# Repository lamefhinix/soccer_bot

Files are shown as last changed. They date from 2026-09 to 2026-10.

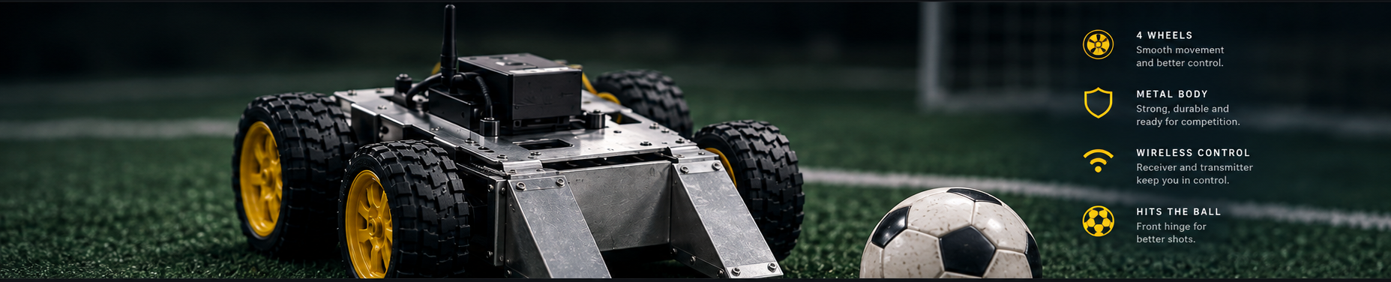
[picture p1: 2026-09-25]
soccer-bot-cover.png

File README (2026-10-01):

description

Soccer Bot is a high-performance four-wheel robot built for competitive soccer matches.
Designed to compete against other powerful robots, it emphasizes power, durability, and precise control.
It uses 500 RPM geared motors, metal wheels, an ESP32 controller, and BTS7960 motor drivers for strong, responsive movement.
The aluminum frame provides a durable yet lightweight foundation.
This project combines mechanical engineering, electronics, wireless control, and software for a reliable, competition-ready soccer robot.

motor driver 


main CPU


Bill of Materials


1.Four pcs 37GB 600 RPM motors

2.four pcs wheels with metal rims

3.20x20 cm PVC frame

4.four pcs Motor Driver 43A BTS7960

5.DC DC Buck Converter LM2596 with Display

6.ESP32 S3 DevKitC1 N16R8 Development Board Dual USB Type C 18650

7.12V 7000mAh (84Wh) Lithium-ion Rechargeable Battery Pack with 40A BMS

8.Radiomaster Pocket Radio Controller (M2) 9.RadioMaster ER6 2.4 GHz ELRS PWM receiver

9.ball-handling mechanisms

10.soldering iron

1.Four pcs 37GB 600 RPM motors


description 
The motors power the robot's wheels, so it can move and turn quickly during a match Estimated price: 8.95 dollars × 4 pcs Buy link: https://electronics.com.bd/12v-500-rpm-high-torque-dc-gear-motor-37gb555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

2.Four pcs 65mm Rubber Wheel With Metal rim

description Four 65 millimeter metal rim wheels with rubber tires. Provide traction and transfer motor power to the ground for movement and turning. Estimated price: 16.25 dollars Buy link: https://radiogearbd.com/product-details/65mm-rubber-wheel-with-metal-rim-4pcs-set-for-robo-soccer

3.20x20 cm PVC frame self-funded
4.four pcs of motor driver 43A BTS7960
**

description BTS7960 motor driver module controls one DC motor, allowing independent speed and direction control Estimated price: 3.98 Doller × 4 pcs Buy link: https://store.roboticsbd.com/imugyrocompass/742-motor-driver-43a-bts7960-robotics-bangladesh.html

5.DC DC Buck Converter LM2596 with Display

description DC-DC buck converter: steps down battery voltage to a stable lower voltage for ESP32 and receiver Estimated price: 3.17 Doller × 1 pcs Buy link: https://store.roboticsbd.com/components/1524-lm2596-dc-dc-step-down-buck-converter-with-digital-tube-display-robotics-bangladesh.html

6.12V 7000mAh (84Wh) Lithium-ion Rechargeable Battery Pack with 40A BMS

description 12 volt 7000 milliamp hour Li-ion rechargeable battery with 40 amp BMS, providing reliable power for robot's motors and electronics Estimated price: 22.77 Doller × 1 pcs Buy link: https://www.daraz.com.bd/products/12v-7000mah-84wh-lithium-ion-rechargeable-battery-pack-with-40a-bms-1000-life-i328284264.html

7.ESP32 S3 DevKitC1 N16R8 Development Board Dual USB Type C


description ESP32 DevKit-C1, main control board that processes receiver commands and controls the four BTS7960 motor drivers for precise speed and direction control. Estimated price: 8.1 Doller × 1 pcs Buy link: https://techshopbd.com/product/esp32-s3-devkitc1-n16r8-development-board-dual-usb-type-c

8.Radiomaster Pocket Radio Controller (M2) ELRS Version

description RadioMaster Pocket M2 ELRS, wireless transmitter used to remotely control the robot's movement and speed Estimated 
price: 71.50 Doller × 1 pcs
Buy link: https://radiomasterrc.com/products/pocket-radio-controller-m2

9.ER4 2.4GHz ELRS PWM Receiver


10.WEMON 936 Soldering Iron 90W Intelligent Digital Display Portable 120~550℃ Adjustable 900M Series tools Kit price: 10.00 dollars × 1 pcs

Estimated total: 198.51 dollars



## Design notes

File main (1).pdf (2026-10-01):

# Robo Soccer Robot

## Product Requirements Document

### Parametric concept, interfaces, and CAD handoff specification

Prepared by Manus AI
Date: 2026-10-01

Design status: concept-level, dimensioned for CAD handoff. Fabrication status: do not manufacture until all placeholder hardware dimensions are measured.

## Contents

Robo Soccer Robot — Product Requirements Document | Manus AI

## 1 Executive summary

This document defines a compact four-wheel-drive robo-soccer platform based on a 200 mm × 200 mm square-tube chassis, 65 mm wheels, four geared motors, four BTS7960 motor drivers, an ESP32-class controller, a 12 V battery, a radio receiver, and a front ball-contact bracket. The design prioritizes a low center of gravity, serviceability, inboard wheels, and a footprint that remains below the 250 mm × 250 mm competition envelope.
The accompanying CAD sources include an editable CadQuery generator and an exported STEP assembly. The assembly shows the major parts, the mechanical stack-up, electronics envelopes, and the major service interfaces. The source intentionally distinguishes fixed, derived, and interface-parameterized dimensions so that a later CAD pass can replace manufacturer-specific details without silently changing the design intent.

The first engineering gate is dimensional verification: measure the actual tube, wheel, motor gearbox, battery, driver heatsink, receiver, and controller before releasing fabrication drawings.

## 2 Product definition

## 2.1 Objective

Build a robust, serviceable robot that can drive, turn, and interact with a soccer ball inside a maximum 250 mm × 250 mm footprint. The robot should keep heavy components low, protect wiring from wheel motion, and expose enough access for rapid battery and electronics service.

## 2.2 Intended use

- Indoor or smooth-field robo-soccer prototype.
- Four-wheel drive with independent motor control.
- Front ball-contact bracket with a nominal 70 mm opening.
- Manual radio control in the first integration phase; autonomous strategy is a future extension.

## 2.3 Success criteria

ID | Target | Acceptance evidence
PR-01 Footprint | ≤ 250 × 250 mm | Measured assembled envelope including wheels and bracket
PR-02 Chassis | 200 × 200 mm | CAD inspection and tape-measure check
PR-03 Drive | 4 independently driven wheels | Bench test of all four channels
PR-04 Serviceability | Battery removable without tools | Remove/install demonstration
PR-05 Stability | CG height ≤ 55 mm target | Mass-property estimate after hardware selection

PR-06 Ball interface | 70 mm nominal opening | Ball-contact fit check
PR-07 Electrical safety | Upstream disconnect | Continuity and fault-isolation test

## 3 System architecture

## 3.1 Coordinate system and design intent

The CAD origin is at the chassis center on the floor-pan reference plane. +X points forward toward the ball bracket, +Y points to the left side of the robot, and +Z points upward. All dimensions in this document and in the CAD source are millimetres unless stated otherwise.
The primary layout is symmetric about both center planes. The two 200 mm longitudinal rails sit at Y = ±90 mm. Two 160 mm cross rails sit at X = ±90 mm, inside the longitudinal rails. The resulting outer structural envelope is 200 mm × 200 mm.

## 3.2 Functional blocks

Block | Function | Interfaces
Energy | Store and distribute 12 V power | Battery, fuse/disconnect, motor-driver power, buck converter
Drive | Convert commands into wheel torque | ESP32 PWM/DIR → BTS7960 → four motors
Control | Run manual-control firmware and future strategy | ESP32, receiver input, serial/ programming header
Motion | Translate wheel torque into field motion | Four wheels, four motor mounts, floor clearance
Ball | Guide/contact the ball at the front | 70 mm opening, low capture bar, replaceable liner

## 4 Mechanical requirements

## 4.1 Global parameters

Parameter | Value | Status | Engineering note
FOOTPRINT_MAX | 250 × 250 | Fixed | Competition envelope limit
CHASSIS_L / CHASSIS_W | 200 / 200 | Fixed | Square-tube outer structure
TUBE | 20 × 20 | Placeholder | Measure actual PVC tube; model currently assumes 20
WHEEL_D | 65 | Fixed | Wheel diameter used for axle height

WHEEL_W | 25 | Fixed by brief | Verify hub protrusion and bore before machining
EDGE_CLEARANCE | 15 | Fixed target | Symmetric inboard wheel placement
MOTOR_D / MOTOR_L | 37 / 63 | Fixed envelope | 37GB-family envelope; gearbox hole pattern remains editable
MOTOR_SHAFT_D / L | 6 / 15 | Placeholder | D-shaft flat orientation matters
BATT_L / W / H | 150 / 45 / 45 | Fixed envelope | 12 V, 7000 mAh envelope from brief; verify connector exit
BTS_L / W / H | 50 / 50 / 40 | Fixed envelope | Simplified board/heatsink solid; verify exact mounting pattern
GROUND_CLEARANCE | ≈ 22 | Derived | 65/2 minus approximately 10 mm chassis drop

## 4.2 Chassis and drivetrain geometry

- Wheel centers are at (X, Y) = (±72.5, ±72.5) mm.
- Track and wheelbase are both 145 mm.
- Wheel axles are nominally collinear at Z = 32.5 mm.
- Wheels are inboard. Outboard wheels would push the envelope to approximately 255 mm across and violate the 250 mm limit.
- Add a 5 mm relief slot in each tube wall at the wheel well after the real wheel and tube geometry are measured.
- Heavy components sit on or near the floor pan. Target CG height is no more than 55 mm.

## 4.3 Motor mount requirements

Each corner uses a mirrored L-bracket made from 3 mm aluminium or printed PETG. The bracket shall provide:
1. A motor face plate with four M3 holes on the measured gearbox pattern.
2. Two vertical-leg M3 adjustment slots allowing approximately ±2 mm axle-height correction.
3. Two M3 through-bolts into the tube using T-nuts or captive nuts.
4. A mount datum that keeps all four axles collinear after adjustment.
5. A replaceable interface between the gearbox and the bracket so motor replacement does not require frame disassembly.

## 5 Electronics and wiring

## 5.1 Placement

The battery is centered at X = 0, Y = 0 on the floor pan. It is held with hook-and-loop and two removable retainers bolted to the cross rails. Four BTS7960 drivers occupy open positions around the battery at nominal centers (±60, 0) and (0, ±60), each on four 10 mm M3 standoffs. This leaves airflow around the heatsinks and keeps high-current motor wiring short.

The ESP32 board, buck converter, and receiver form the controller stack near the front/side service area. The CAD model shows their nominal envelopes, not their exact PCB hole patterns; verify the selected board variants before drilling.

## 5.2 Electrical interface contract

Interface | From | To | Requirement
BAT+ / BAT− | 12 V battery | Fuse/disconnect and power bus | Use a single upstream disconnect; common ground throughout
MOTOR_PWR | 12 V bus | BTS7960 ×4 | Route high-current pairs away from receiver and signal wires
MOTOR_OUT ×4 | BTS7960 | Gear motors | One driver per motor; label left/ right and front/rear
PWM/DIR ×4 | ESP32 | BTS7960 inputs | Use four independent channels; reserve GPIOs in firmware map
5 V LOGIC | Buck converter | ESP32 + receiver | Verify regulator current margin and connector polarity
RC SIGNAL | Receiver | ESP32 | Define PWM/PPM/serial protocol before harness fabrication
DEBUG/PROG | USB/UART header | ESP32 | Accessible without removing battery

## 5.3 Wiring and safety requirements

- Add an appropriately sized fuse or resettable protection upstream of the motor-driver bus.
- Use a keyed or polarized connector for the battery and a physically protected power switch/disconnect.
- Separate high-current motor pairs from receiver antenna and controller signal wiring.
- Provide strain relief at every connector that leaves the floor pan.
- Label all four motor channels at both ends of the harness.
- Confirm motor-driver logic voltage compatibility with the selected ESP32 board.
- Provide a single-point common ground and verify it with a continuity test before powering the controller.

## 6 Software and control requirements

## 6.1 Minimum control behavior

The first firmware milestone shall support:
- Arm/disarm state with an explicit safe default after boot.
- Independent output for four motor channels.
- Radio-loss timeout that commands all motor outputs to zero.
- Battery-voltage telemetry or at least a low-voltage warning input in the architecture.
- Direction and inversion parameters per wheel so wiring orientation is configurable.
- A test mode that spins one motor at a time at low duty cycle.

## 6.2 Future extension points

Reserve software and wiring capacity for wheel-speed sensing, a camera or range sensor, and autonomous ball strategy. These are intentionally not modeled as purchased hardware in the first CAD release.

## 7 CAD deliverable specification

## 7.1 Included source model

The deliverable includes robo_soccer_bot_assembly.step, a real multi-solid STEP assembly that re-imports successfully through a STEP-capable CAD kernel, plus robo_soccer_cad.py, its editable CadQuery generator. The earlier OpenSCAD source remains available as a lightweight parametric reference. The CAD deliverables include:
- Frame rails, floor pan, and service deck.
- Four wheels with hubs and four motor pods.
- Mirrored L-bracket motor mounts with fastener markers.
- Battery envelope and removable retainer rails.
- Four BTS7960 envelopes with standoff markers.
- ESP32, buck, and radio-receiver envelopes.
- Front ball bracket, opening, and low capture bar.
- EXPLODED, SHOW_WHEELS, SHOW_ELECTRONICS, and SHOW_FASTENERS toggles.
Open the STEP file in FreeCAD, Fusion 360, SolidWorks, or another STEP-capable CAD tool. The native CadQuery generator exposes editable interface parameters, including the motor gearbox hole spacing. The accompanying SVG files provide CAD-derived top and isometric views.

## 7.2 Assembly sequence

1. Cut and deburr the two longitudinal and two cross rails.
2. Assemble the square frame and verify 200 mm outer dimensions.
3. Install the floor pan and check that it does not interfere with wheel sweep.
4. Fit the four motor brackets loosely, set axle height, and verify collinearity.
5. Install motors and wheels; rotate by hand through a full revolution.
6. Install battery retainers and confirm tool-free battery removal.
7. Install the four drivers on standoffs with open airflow paths.
8. Install controller stack, receiver, and buck converter.
9. Route and label the harness, then perform continuity checks before energizing.
10. Fit the ball bracket and verify the final footprint remains within 250 mm × 250 mm.

## 8 Verification and test plan

ID | Test | Method | Pass condition
V-01 | Envelope | Measure max X/Y including wheels and bracket | Both ≤ 250 mm
V-02 | Wheel clearance | Rotate each wheel by hand with chassis mounted | No rub or hard spot

V-03 | Axle alignment | Straightedge or datum measurement | All axle centers collinear
V-04 | Battery service | Remove/install without tools | No frame disassembly
V-05 | Driver cooling | Low-speed and sustained bench run | No unsafe heat rise; airflow clear
V-06 | Electrical isolation | Continuity, polarity, and disconnect test | No short; disconnect removes drive power
V-07 | Channel mapping | Run one motor at a time | Correct direction and label
V-08 | Ball interface | Fit intended ball and push against bracket | Stable contact without wheel interference

## 9 Risks, assumptions, and open decisions

## 9.1 High-priority risks

- Actual battery connector and cable-exit dimensions may affect service access.
- The selected motor gearbox hole pattern or shaft geometry may differ from the 37GB-family envelope; the interface is intentionally parameterized.
- BTS7960 mounting details may differ from the simplified 50 × 50 × 40 mm solid.
- The front ball bracket may change the footprint if its liner or capture geometry projects beyond the 250 mm limit.
- PVC tube wall thickness and fastener access may require local reliefs not represented in this concept model.

## 9.2 Open decisions before release to manufacture

1. Confirm the exact motor, wheel, battery, driver, ESP32, buck, and receiver part numbers.
2. Confirm manufacturer-specific interfaces and update the CAD parameters where required.
3. Choose the final tube material and joining method: printed corner blocks, aluminium angle, or direct fasteners.
4. Select fuse rating, wire gauges, connectors, and an emergency disconnect.
5. Confirm field rules for ball size, robot envelope, and allowed materials.
6. Decide whether a protective top cover is required after the first drive test.

## 10 Release checklist

[ ] Manufacturer-specific interfaces verified and editable parameters updated. [ ] CAD assembly opens and exports without geometry collisions.
[ ] Footprint and wheel clearance verified on the assembled prototype.
[ ] Electrical harness labeled, fused, and polarity-checked.
[ ] Safe boot, radio-loss timeout, and one-motor-at-a-time test completed. [ ] Ball bracket and service access approved by the build owner.

## 11 Appendix: parameter handoff

Coordinate system: X forward, Y left/right, Z up

Fixed: CHASSIS_L=200, CHASSIS_W=200, FOOTPRINT_MAX=250, WHEEL_D=65

Derived: WHEEL_X=72.5, WHEEL_Y=72.5, AXLE_Z=32.5

Interfaces to verify: TUBE, wheel hub/bore, gearbox hole pattern, shaft D/L,

battery connector exit, BTS mounting pattern, ESP32 variant, buck, receiver

Interfaces: 12V power bus; 4x motor outputs; 4x PWM/DIR;

5V logic; receiver signal; USB/UART debug; upstream disconnect

End of document — concept design release pending hardware measurement

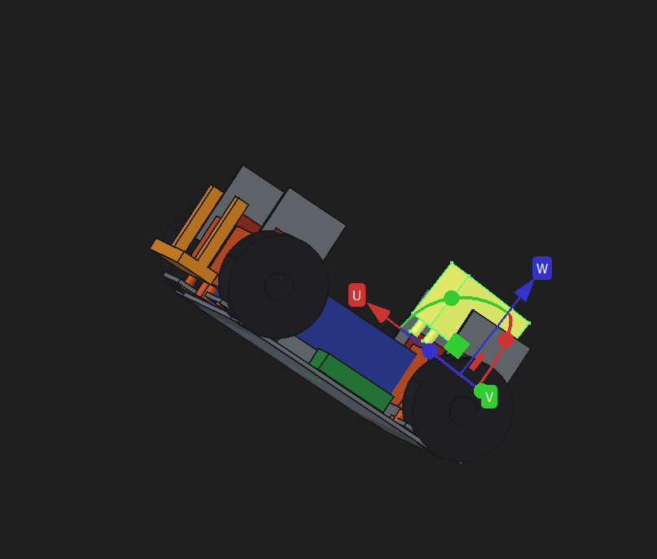
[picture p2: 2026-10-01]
Screenshot 2026-10-01 154059.png

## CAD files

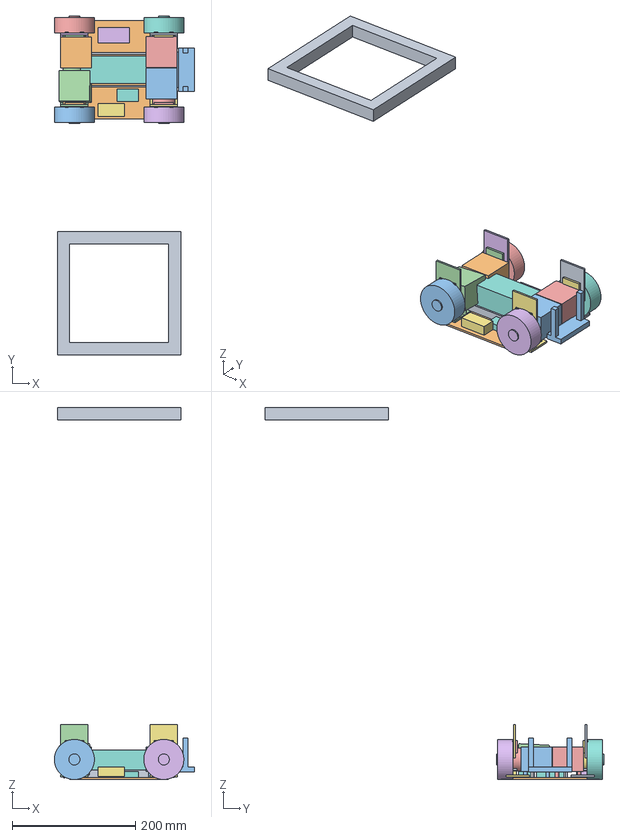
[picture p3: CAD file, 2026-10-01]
CADmd.FCStd
227.4 x 549.0 x 603.0 mm
Chassis
Floor_Pan
Front_Ball_Bracket
Motor_FL
Wheel_FL
Motor_Mount_FL
Motor_FR
Wheel_FR
Motor_Mount_FR
Motor_RL
Wheel_RL
Motor_Mount_RL
Motor_RR
Wheel_RR
Motor_Mount_RR
Battery_12V_7000mAh
Battery_Retainers
BTS7960_FL
BTS7960_FR
BTS7960_RL
BTS7960_RR
ESP32
Buck_Converter
Radio_Receiver
Fasteners

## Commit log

2026-09-27 Modify motor details in HARDWARE.md
    Updated image and description for motors in hardware list.
2026-09-28 Create Bill of Materials
2026-09-28 Update Bill of Materials
2026-09-29 Rename Bill of Materials to Bill ofMaterials
2026-09-29 Add Bill of Materials file
